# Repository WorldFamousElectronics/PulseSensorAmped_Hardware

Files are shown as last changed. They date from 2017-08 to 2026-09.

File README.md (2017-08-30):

# PulseSesorAmped_Hardware
These files were created in [Design Spark](http://www.designspark.com/) Schematic Layout and PCB Capture Software 

You will need to copy the contents of DesignSparkLibraryFiles into the default Library that Design Spark uses. Normally something like 

`Documents\DesignSpark PCB\Library`

This is the only way you will be able to use or modify the APDS-9008 part or the reverse mount LED part.

CONTRIBUTORS BACKTRACK AND NOTIFICATION

joel@pulsesensor.com
yury@pulsesensor.com

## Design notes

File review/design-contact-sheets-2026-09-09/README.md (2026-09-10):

# PulseSensor design contact sheets — 2026-09-09

DEVELOPMENT / visual reference review only. No board design changes or fabrication release.

27 numbered designs, paired front/back. Missing views are labeled; no different board is substituted. The nine SVG concepts are back-only illustrations. Existing renders are resized and padded faithfully, with no crop, recoloring, or reconstruction. Render colors may differ from intended manufacturing colors.

## Contact sheets

### Sheet 01: designs 01–03
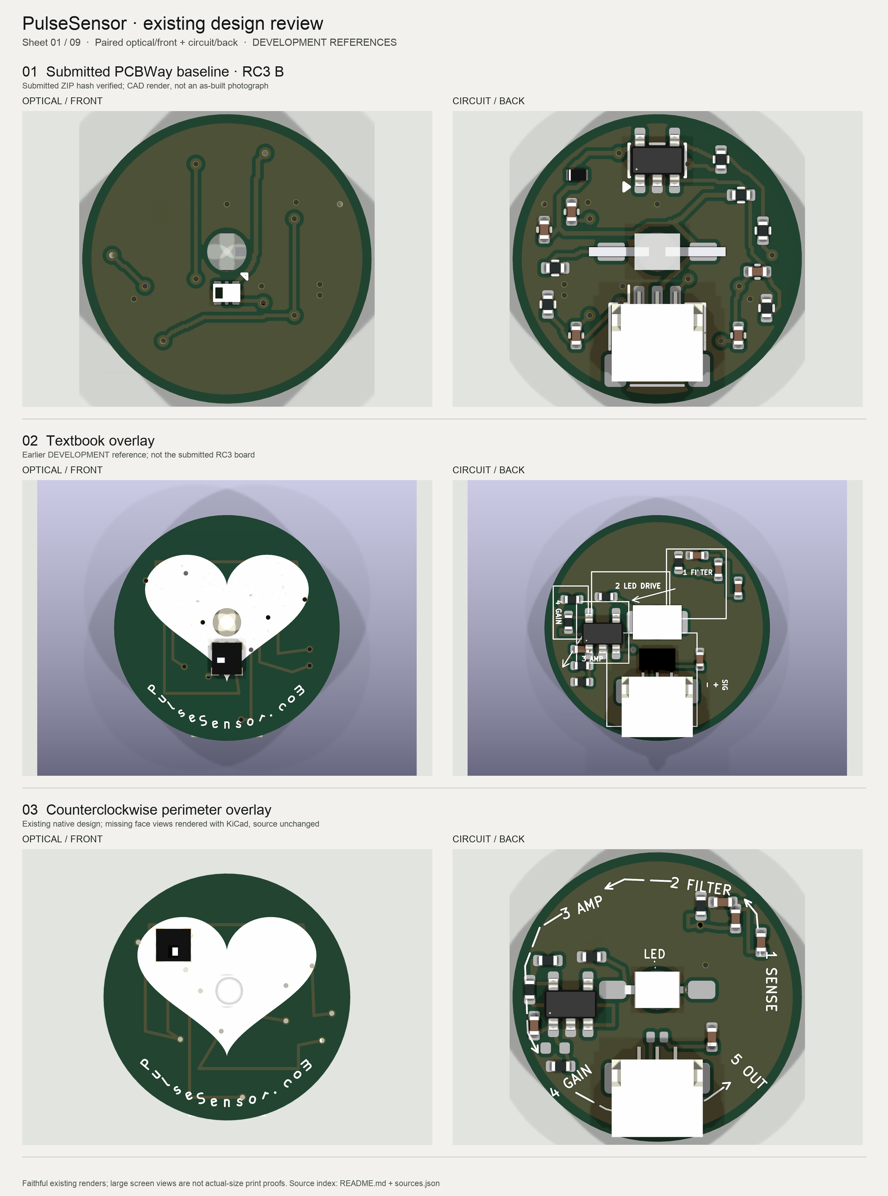
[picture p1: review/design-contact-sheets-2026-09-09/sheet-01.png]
Sheet 01


### Sheet 02: designs 04–06
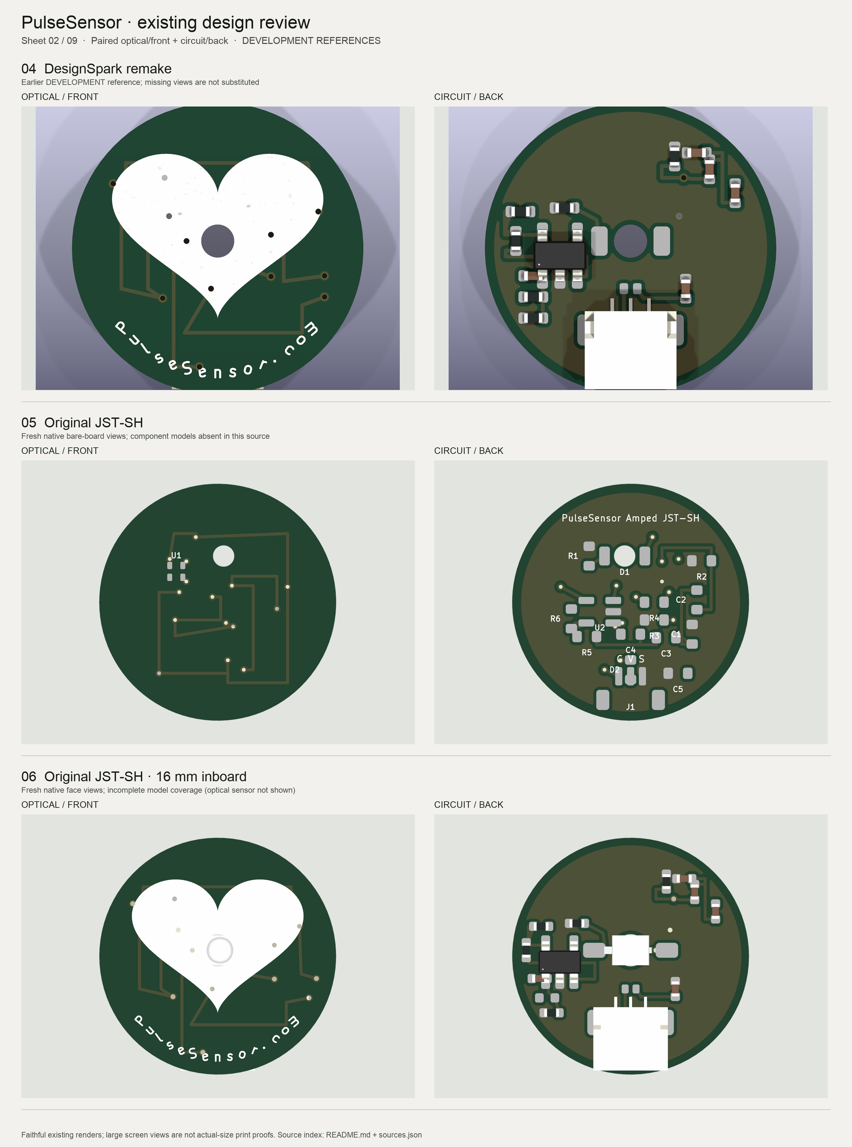
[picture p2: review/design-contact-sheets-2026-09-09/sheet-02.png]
Sheet 02


### Sheet 03: designs 07–09
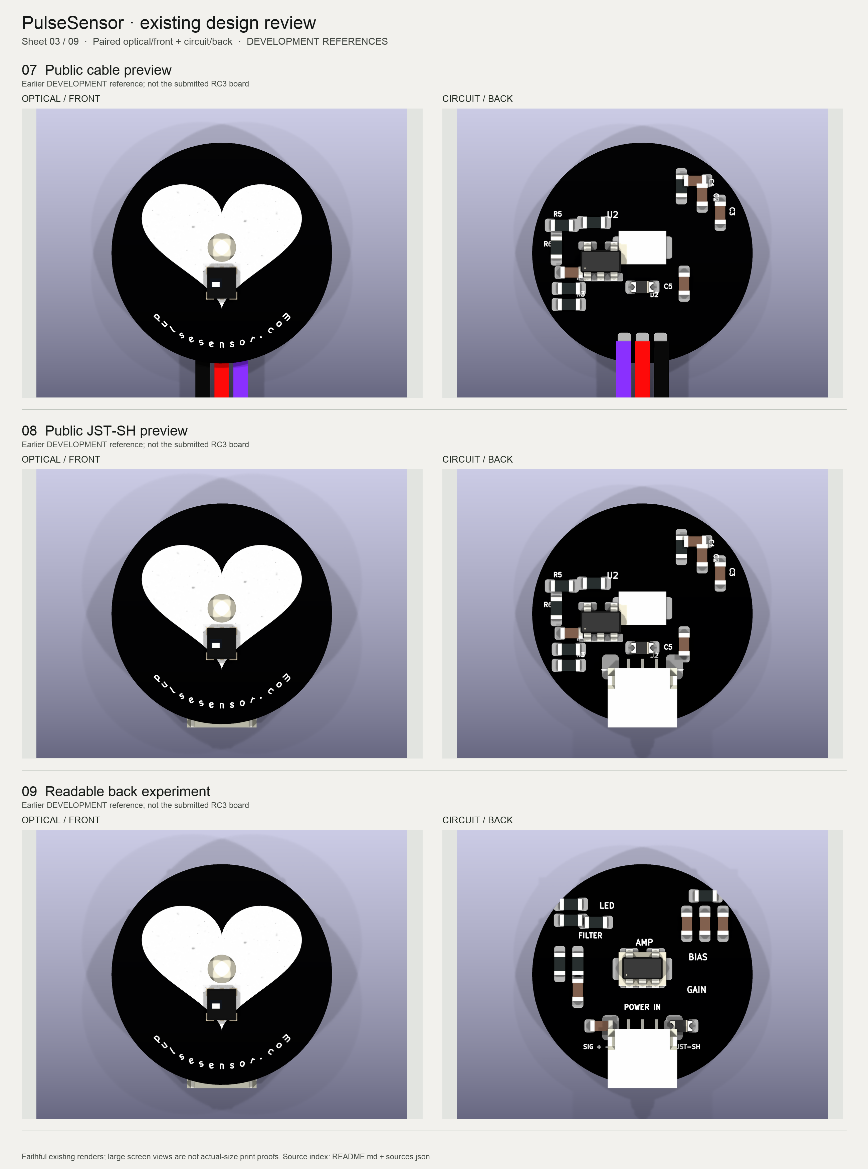
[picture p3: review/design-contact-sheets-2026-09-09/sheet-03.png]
Sheet 03


### Sheet 04: designs 10–12
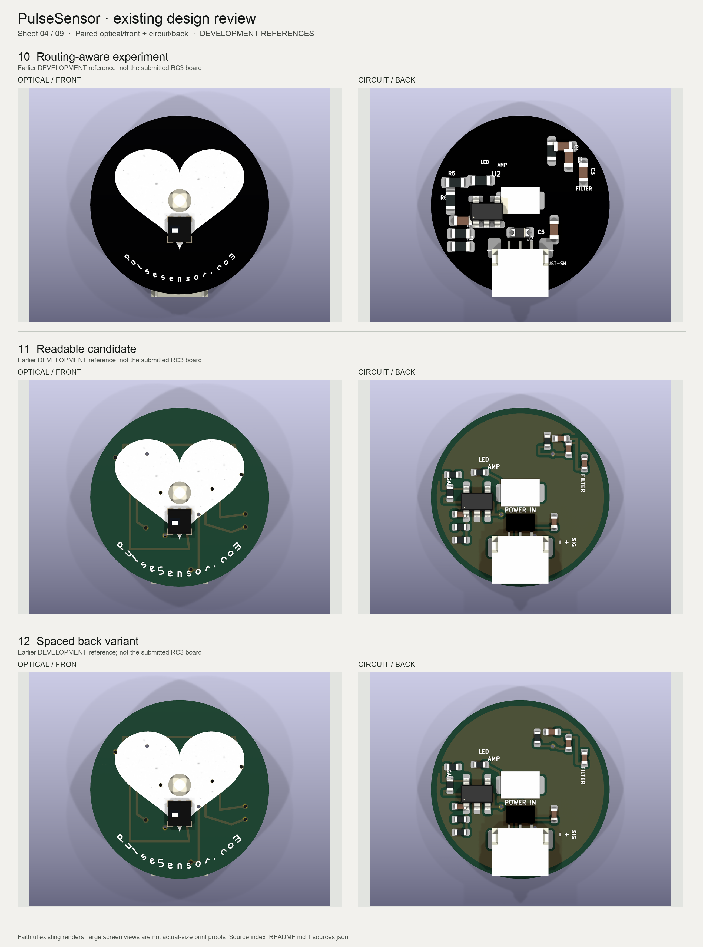
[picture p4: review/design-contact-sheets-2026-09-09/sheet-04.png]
Sheet 04


### Sheet 05: designs 13–15
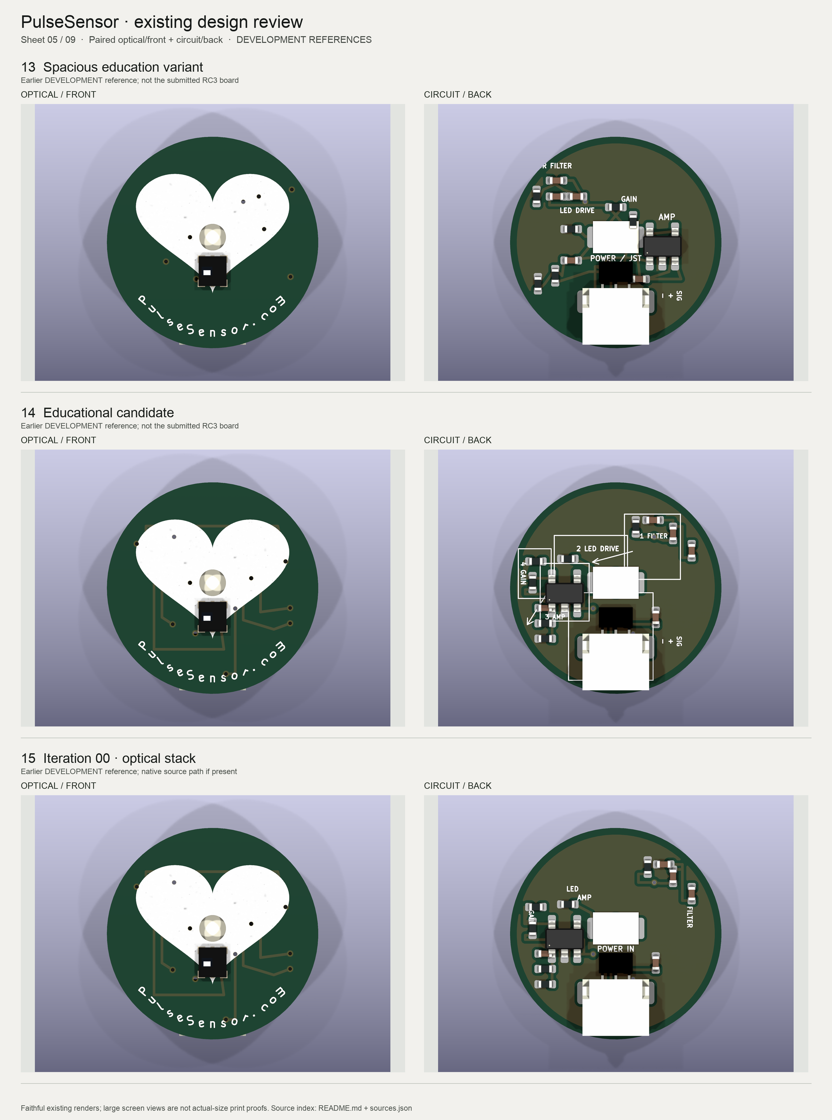
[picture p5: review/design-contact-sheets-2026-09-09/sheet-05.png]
Sheet 05


### Sheet 06: designs 16–18
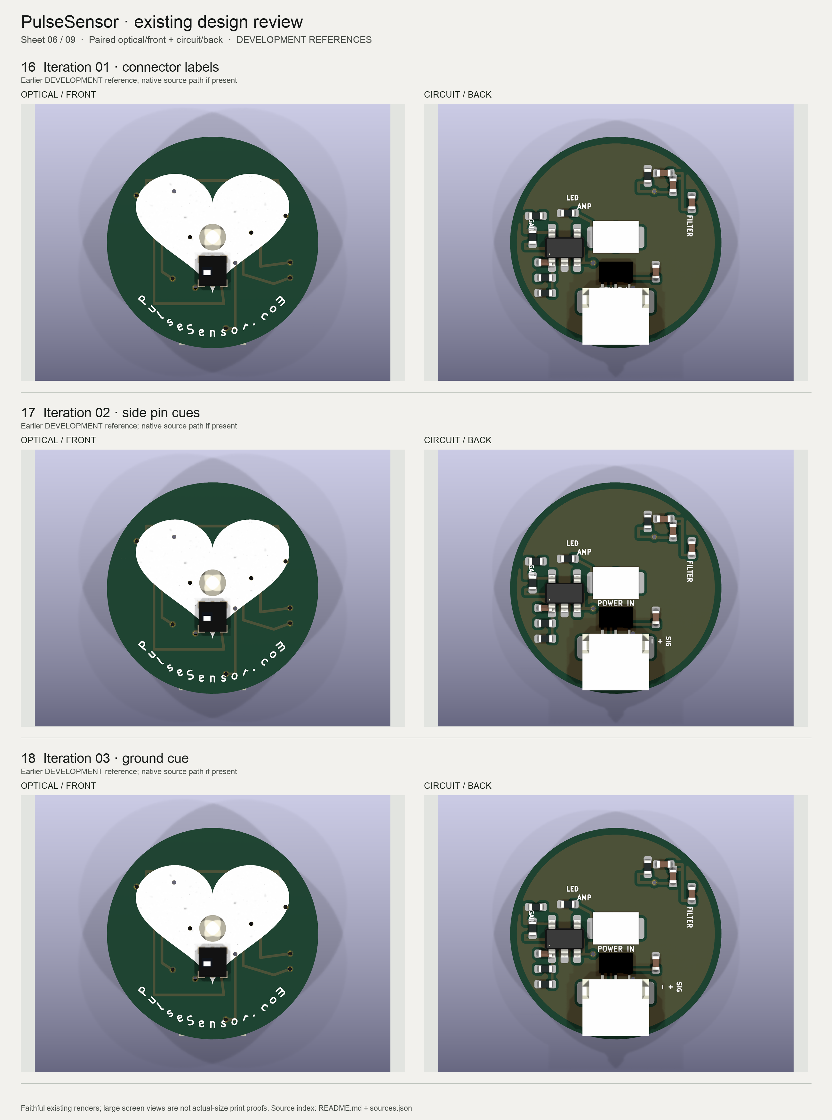
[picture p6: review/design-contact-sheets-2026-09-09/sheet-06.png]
Sheet 06


### Sheet 07: designs 19–21
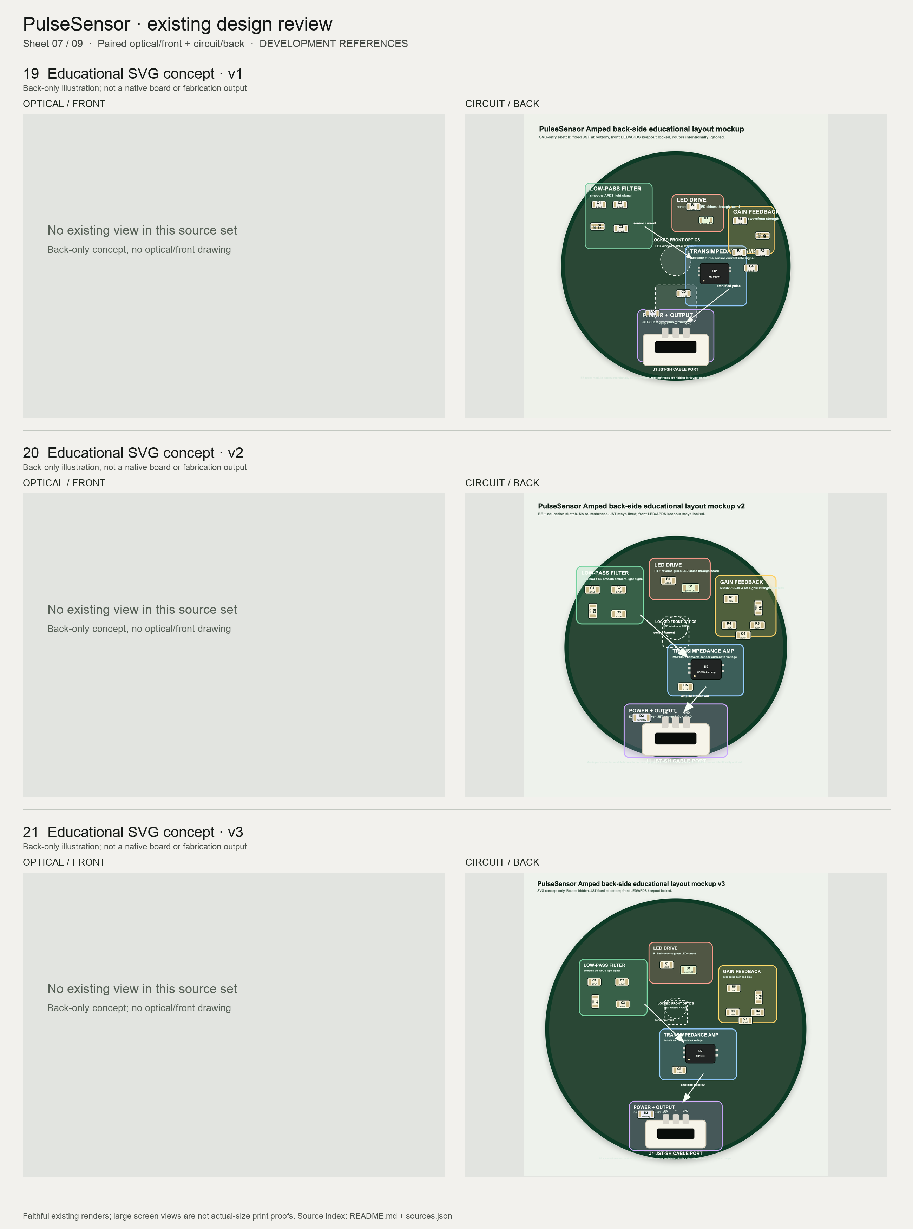
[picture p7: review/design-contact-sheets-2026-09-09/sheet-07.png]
Sheet 07


### Sheet 08: designs 22–24
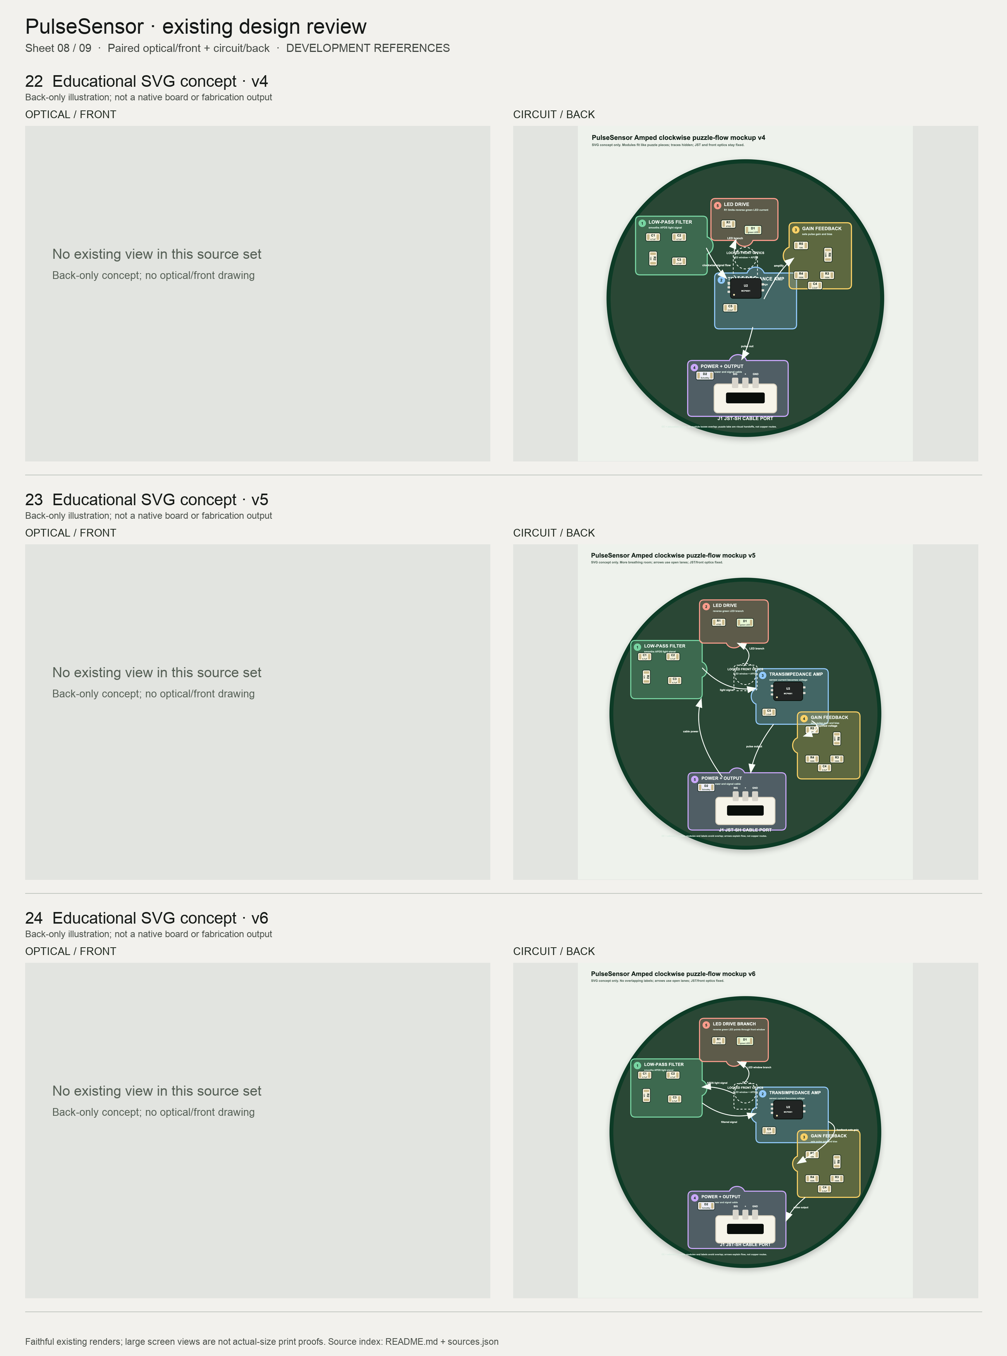
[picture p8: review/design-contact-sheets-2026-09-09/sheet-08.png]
Sheet 08


### Sheet 09: designs 25–27
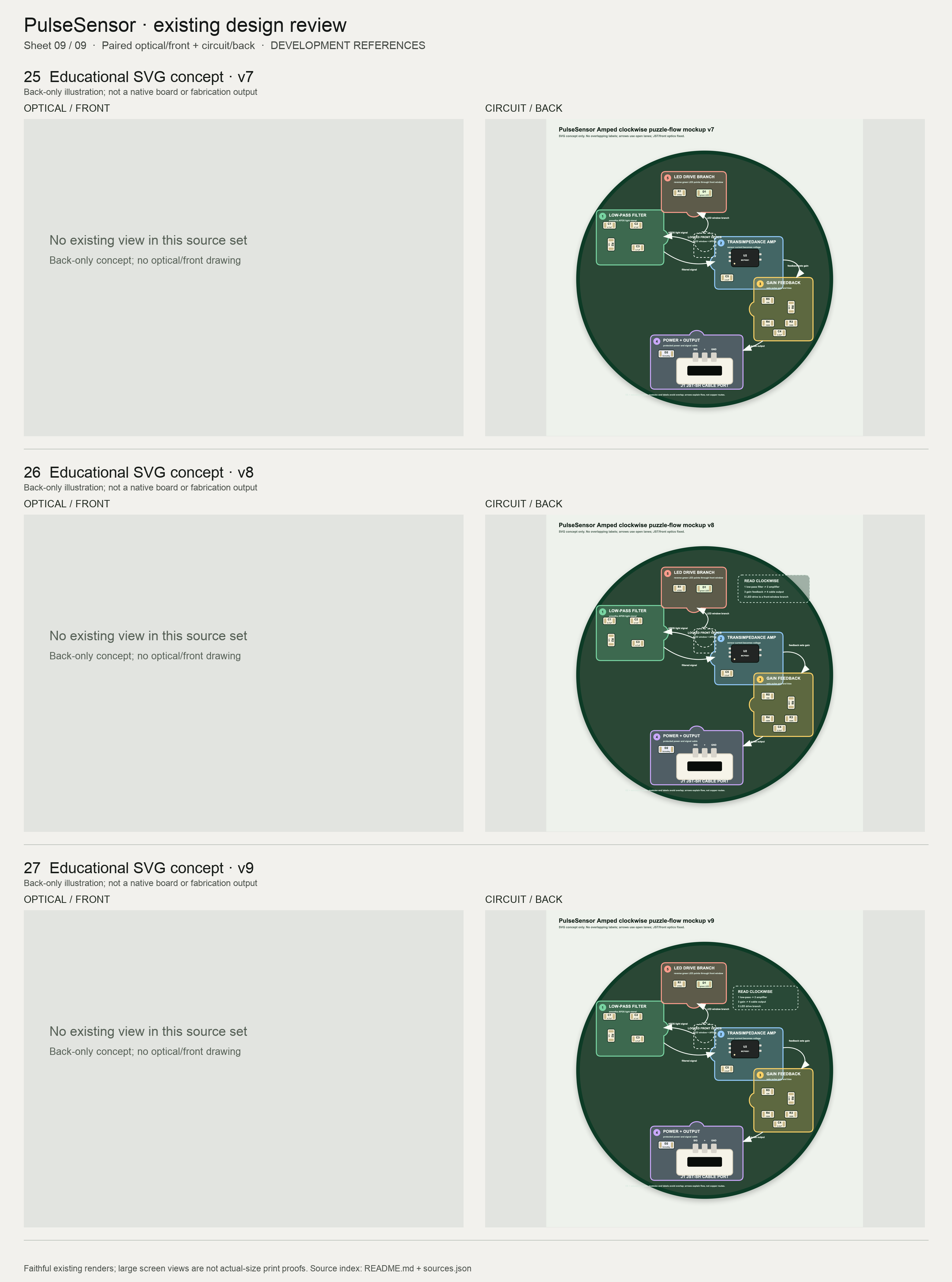
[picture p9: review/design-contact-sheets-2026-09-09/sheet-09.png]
Sheet 09


## Source index

Exact local source paths, SHA-256 hashes, source checkout revisions, tracked flags, and per-file dirty status are in [sources.json](sources.json). A checkout revision alone does not identify dirty or ignored artifacts: use the recorded file hash. Source files remain untouched.

| No. | Design | Source folder / native file |
| --- | --- | --- |
| 01 | Submitted PCBWay baseline · RC3 B | `PulseSensor-Amped-Rebuild/output/pcbway-release-candidates-RC3-R1-FINAL/PulseSensor-Amped-B-PCBWay-EVT-RC3-R1-FINAL/SOURCE_SUPPORT/PulseSensor-Amped-B-JST.kicad_pcb` |
| 02 | Textbook overlay | `Public-Online-Audit/KiCad-Public-3D-View-JSTSH-Textbook-Overlay-Variant/PulseSensorAmped_Public_Online_3D_View_JSTSH_Textbook_Overlay_Variant.kicad_pcb` |
| 03 | Counterclockwise perimeter overlay | `PCBWay-Fresh-Spin-2026-07-31-Isolated/02-counterclockwise-overlay/PulseSensorAmped_Fresh_CCW_Overlay.kicad_pcb` |
| 04 | DesignSpark remake | `KiCad-DesignSpark-Remake/PulseSensorAmped_DesignSpark_Remake.kicad_pcb` |
| 05 | Original JST-SH | `KiCad-Original-JSTSH/PulseSensorAmped_Original_JSTSH.kicad_pcb` |
| 06 | Original JST-SH · 16 mm inboard | `KiCad-Original-JSTSH-16mm-inboard/PulseSensorAmped_Original_JSTSH_16mm_inboard.kicad_pcb` |
| 07 | Public cable preview | `Public-Online-Audit/KiCad-Public-3D-View/PulseSensorAmped_Public_Online_3D_View.kicad_pcb` |
| 08 | Public JST-SH preview | `Public-Online-Audit/KiCad-Public-3D-View-JSTSH-Variant/PulseSensorAmped_Public_Online_3D_View_JSTSH_Variant.kicad_pcb` |
| 09 | Readable back experiment | `Public-Online-Audit/KiCad-Public-3D-View-JSTSH-Readable-Back-Experiment/PulseSensorAmped_Public_Online_3D_View_JSTSH_Readable_Back.kicad_pcb` |
| 10 | Routing-aware experiment | `Public-Online-Audit/KiCad-Public-3D-View-JSTSH-Routing-Aware-Experiment/PulseSensorAmped_Public_Online_3D_View_JSTSH_Routing_Aware.kicad_pcb` |
| 11 | Readable candidate | `Public-Online-Audit/KiCad-Public-3D-View-JSTSH-Readable-Production-Candidate/PulseSensorAmped_Public_Online_3D_View_JSTSH_Readable_Production_Candidate.kicad_pcb` |
| 12 | Spaced back variant | `Public-Online-Audit/KiCad-Public-3D-View-JSTSH-Spaced-Back-Variant/PulseSensorAmped_Public_Online_3D_View_JSTSH_Spaced_Back_Variant.kicad_pcb` |
| 13 | Spacious education variant | `Public-Online-Audit/KiCad-Public-3D-View-JSTSH-Spacious-Education-Variant/PulseSensorAmped_Public_Online_3D_View_JSTSH_Spacious_Education_Variant.kicad_pcb` |
| 14 | Educational candidate | `Public-Online-Audit/KiCad-Public-3D-View-JSTSH-Educational-Production-Candidate/PulseSensorAmped_Public_Online_3D_View_JSTSH_Educational_Production_Candidate.kicad_pcb` |
| 15 | Iteration 00 · optical stack | `Public-Online-Audit/Readable-Production-Design-Loops/iteration-00-fixed-optical-stack/renders/back.png` |
| 16 | Iteration 01 · connector labels | `Public-Online-Audit/Readable-Production-Design-Loops/iteration-01-connector-label-pass/renders/back.png` |
| 17 | Iteration 02 · side pin cues | `Public-Online-Audit/Readable-Production-Design-Loops/iteration-02-side-pin-cues/renders/back.png` |
| 18 | Iteration 03 · ground cue | `Public-Online-Audit/Readable-Production-Design-Loops/iteration-03-visible-ground-cue/renders/back.png` |
| 19 | Educational SVG concept · v1 | `Public-Online-Audit/Educational-SVG-Mockups/pulsesensor_back_educational_layout_mockup.svg` |
| 20 | Educational SVG concept · v2 | `Public-Online-Audit/Educational-SVG-Mockups/pulsesensor_back_educational_layout_mockup_v2.svg` |
| 21 | Educational SVG concept · v3 | `Public-Online-Audit/Educational-SVG-Mockups/pulsesensor_back_educational_layout_mockup_v3.svg` |
| 22 | Educational SVG concept · v4 | `Public-Online-Audit/Educational-SVG-Mockups/pulsesensor_back_clockwise_puzzle_flow_mockup_v4.svg` |
| 23 | Educational SVG concept · v5 | `Public-Online-Audit/Educational-SVG-Mockups/pulsesensor_back_clockwise_puzzle_flow_mockup_v5.svg` |
| 24 | Educational SVG concept · v6 | `Public-Online-Audit/Educational-SVG-Mockups/pulsesensor_back_clockwise_puzzle_flow_mockup_v6.svg` |
| 25 | Educational SVG concept · v7 | `Public-Online-Audit/Educational-SVG-Mockups/pulsesensor_back_clockwise_puzzle_flow_mockup_v7.svg` |
| 26 | Educational SVG concept · v8 | `Public-Online-Audit/Educational-SVG-Mockups/pulsesensor_back_clockwise_puzzle_flow_mockup_v8.svg` |
| 27 | Educational SVG concept · v9 | `Public-Online-Audit/Educational-SVG-Mockups/pulsesensor_back_clockwise_puzzle_flow_mockup_v9.svg` |

## Submitted baseline and reuse boundaries

Design 01 uses the render files and native supporting PCB from the submitted RC3 B archive. The local archive SHA-256 was recomputed as `0afda167b52ab0b0251cf22f91fd92fefa5dcf5e74f67b36446e7ec775acf792`; native PCB bytes were compared directly with its ZIP member. PCB SHA-256: `b439dcff82c4553731ac35ebcd27276899f8dfbbfcd35f2351d8101497eb4ad4`. This establishes archive identity, not as-built equivalence. The original manufacturing Gerbers, BOM and CPL control, rather than the supporting native file.

The submitted RC3 design has optical/front on KiCad B and circuit/back on KiCad F. Earlier versions use different conventions; the paired labels here follow their existing optical/front and circuit/back renders.

Textbook, educational-candidate, and counterclockwise versions demonstrate actual educational silkscreen graphics in native boards. These are block/flow illustrations, not a full component-symbol schematic. They are visual references on older electrical layouts. Their pin maps, geometry, topology and values must not replace the RC3 working baseline. The July counterclockwise folder explicitly declares itself non-authoritative and not for fabrication.

The old white heart and website geometry is photo-reconstructed artwork, not a recovered original silkscreen export (see `Original-Review/original_logo_source_audit.md` in the source checkout). No new artwork or board changes were made for this review.

## Reproduce

Run `build_contact_sheets.py` using Python with Pillow. It reads the approved WFE source checkout paths defined at the top and writes only this review directory. The source hashes record the exact visual inputs used. No email content or supplier correspondence is included.

## Render QA and limitations

All nine sheets were visually reviewed. Five missing/incorrectly named face views were rendered from unchanged existing native boards using KiCad; exact commands and before/after source-hash checks are in `rendered-missing-views/render-evidence.json`. Design 05 has no component models; design 06 has incomplete optical-sensor model coverage. These are source limitations, not assembly instructions. Design 04 also has incomplete legacy model coverage. No missing parts were invented. All native sources remain byte-for-byte unchanged.

## Added artwork, routing and power/color revisions

Original sheets 01–09 remain unchanged. This appendix adds corrected teaching artwork, retained native routing/artwork milestones, and the enlarged-front / color-print candidates. Metadata-helper failures are explicitly labeled. All partial routing checkpoints remain linked in the local visual ledger.

[sheet-10.png](sheet-10.png)

[sheet-11.png](sheet-11.png)

[sheet-12.png](sheet-12.png)

[sheet-13.png](sheet-13.png)

[sheet-14.png](sheet-14.png)

[sheet-15.png](sheet-15.png)

[sheet-16.png](sheet-16.png)

[sheet-17.png](sheet-17.png)

[sheet-18.png](sheet-18.png)

[sheet-19.png](sheet-19.png)

[Current review](../power-color-2026-09-09/review.html) · [All routing attempts and native revision history](../sendoff-candidate-2026-09-09/visual-log/index.html)

### Final selected comparison — sheet 20

[Sheet 20](sheet-20.png) adds the final color-10 candidate. Color-09 on sheet 19 is superseded; its brown optical-front rendering is a retained renderer defect, not intended solder mask. Color-10 still encounters KiCad mixed-mask rendering limitations; the shared black optical-face design is shown from verified mono-08.

## Packaging postcard milestone — 2026-09-10

[Sheet 21](sheet-21.png) shows both 4-inch insert faces: PCB/reference BOM and matching schematic. [Print files and source](../postcard-insert-2026-09-10/README.md). The color-10 board back is accepted as a major milestone; front board graphics are deferred. No hardware geometry changed.

## Complete schematic companion — 2026-09-10

[Sheet 22](sheet-22.png) adds a separate 4-inch card with the complete circuit and a six-part reading guide. [Print files, source and preserved draft](../schematic-companion-2026-09-10/README.md). The first PCB/BOM card and all hardware remain unchanged.

## Puzzle module alternative — 2026-09-10

[Sheet 23](sheet-23.png) compares accepted color-10 with interlocking solid-color functional areas. [Vector study and revision record](../puzzle-modules-2026-09-10/README.md). No hardware changes.

## Dotted module alternative — 2026-09-10

[Sheet 24](sheet-24.png) compares accepted color-10 with straight solid-color functional areas with black dotted boundaries. [Vector study and revision record](../module-outlines-2026-09-10/README.md). No hardware changes.

## Full-color full schematic retail purchase card — 2026-09-10

[Sheet 25](sheet-25.png) adds a separate 4-inch card with the complete circuit and a parts schedule. [Print files, source and preserved draft](../full-color-retail-card-2026-09-10/README.md). The first PCB/BOM card and all hardware remain unchanged.

## Brand unification — 2026-09-10

[Sheet 26](sheet-26.png) shows matching website-sourced salmon and neutral colors on the board and both purchase-card faces. [Palette evidence, print PDFs and color-only checks](../brand-unification-2026-09-10/README.md). All earlier geometry and text preserved.

## WebSerial color iteration — 2026-09-10

[Sheet 27](sheet-27.png) shows matching WebSerial accent colors on the board and both purchase-card faces. [Palette evidence, print PDFs and color-only checks](../webserial-palette-2026-09-10/README.md). All earlier geometry and text preserved.

## WebSerial color iteration — 2026-09-10

[Sheet 28](sheet-28.png) shows matching WebSerial accent colors on the board and both purchase-card faces. [Palette evidence, print PDFs and color-only checks](../led-green-power-red-2026-09-10/README.md). All earlier geometry and text preserved.

## Quiet engineering trial — 2026-09-10

[Sheet 29](sheet-29.png) shows muted board colors and matching pale card tints on the board and both purchase-card faces. [Palette evidence, print PDFs and color-only checks](../quiet-engineering-2026-09-10/README.md). All earlier geometry and text preserved.

## Six-color brand trial — 2026-09-10

[Sheet 30](sheet-30.png) shows white, black, red, green, gray and beige on the board and both purchase-card faces. [Palette evidence, print PDFs and color-only checks](../six-color-brand-2026-09-10/README.md). All earlier geometry and text preserved.

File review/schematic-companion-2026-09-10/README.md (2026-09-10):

# Complete schematic companion postcard

Classification: DEVELOPMENT packaging review proof for the JST revision. This does not promote the board to shipping-product status.

Separate two-sided 4 × 4 inch card, accompanying the [PCB, legend and reference BOM card](../postcard-insert-2026-09-10/README.md).

- Face A: complete connected circuit, organized into six numbered sections. Every chip and connector pin is explicit, including U1's three intentional no-connects. Matching labels connect between sections; B is the filter-to-amplifier connection.
- Face B: matching six-part reading guide and symbol key. Hardware only.
- Source: color-10 native schematic/netlist. All 16 components and 40 terminals (37 connected + 3 NC) checked against the independent terminal map. PDF wires were inspected visually, not extracted by an electrical connectivity engine.
- R1 is described by function; no numerical resistance is invented. Full reference BOM accompanies this on card 01.
- Vector type and schematic: 6.48 pt pin numbers, 6.72 pt component labels, 7.2 pt reading-guide body. Colors supplement labels; meaning does not depend on color alone.

## Files

[4-inch print PDF](output/pdf/PulseSensor-complete-schematic-4x4.pdf), two 288 × 288 pt pages.

[PDF with 0.125-inch bleed](output/pdf/PulseSensor-complete-schematic-4x4-bleed.pdf), two 306 × 306 pt pages with explicit 288 pt trim boxes.

[Visual review](review.html) · [Contact sheet 22](../design-contact-sheets-2026-09-09/sheet-22.png) · [Verification](verification.json).

The first layout proof is preserved in `iterations/01-complete-schematic/`. The final version fixes crowded diode/filter labels, guide line spacing, and explicitly draws U2's supply connections. Board art and first-card files are unchanged.

## Rebuild

Use the bundled Python runtime with ReportLab, pypdf and Pillow:

```
python3 build_companion.py
python3 verify_card.py
pdftoppm -scale-to 1400 -png output/pdf/PulseSensor-complete-schematic-4x4.pdf output/card
python3 log_companion.py
```

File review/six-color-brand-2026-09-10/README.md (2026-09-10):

# Six-color brand trial

Classification: DEVELOPMENT appearance and packaging review.

[Overview](six-color-overview.png) · [Board vector](six-color-07-back.svg) · [Print card](output/pdf/six-color-retail-purchase-card.pdf) · [Bleed card](output/pdf/six-color-retail-purchase-card-bleed.pdf).

Restricted to white, black, PulseSensor red #FF5A5F, WebSerial LED green #44FF44, gray #C0C0C0 and beige #E7DDC8. Green remains LED; red remains power. Board amplifier area is black with white lettering; lighter areas have black lettering. Card amplifier area uses gray, with black reserved for its schematic and text for readability. Beige supplies the warm packaging tone.

Layouts, physical components and circuit connections remain unchanged. Board label polygons are split at the existing dark-region boundary only to change their fill; no footprint or electrical edits. All 40 terminals in the independent map match the native source and both PDF sizes are checked. Prior versions retained; sheet 30, artifact 67.

This is an appearance study. Manufacturer considerations remain in the prior quiet-engineering reality check; no fabrication files were submitted or ordered.

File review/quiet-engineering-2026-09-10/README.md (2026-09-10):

# Quiet engineering palette trial

Classification: DEVELOPMENT appearance and packaging review.

[Overview](quiet-overview.png) · [Board before/after](board-comparison.png) · [Manufacturer reality check](manufacturer-reality-check.md).

Muted green LED, warm red power, teal filter, slate-blue amplification, dusty-violet bias and neutral-gray sense. White labels on the deep board colors; dark ink over related pale tints on warm-white card stock. This adapts the brand direction rather than claiming exact website color tokens.

Calculated sRGB label contrast: board 5.06–6.42:1; card primary ink 9.77–10.10:1, secondary ink at least 5.96:1. Black board boundaries are at least 3.27:1 against the fills. These are screen checks, not certification of printed legibility or color-vision accessibility. Labels, references, boundaries and the schematic carry meaning independently of color.

[Palette and checks](palette.json) · [Verification](verification.json) · [Board vector](quiet-06-back.svg).

[4-inch card PDF](output/pdf/quiet-engineering-retail-purchase-card.pdf) · [Bleed PDF](output/pdf/quiet-engineering-retail-purchase-card-bleed.pdf).

All board geometry and non-color PDF drawing instructions are unchanged from the earlier layouts; all 40 terminals in the independent map match the CAD netlist. No native hardware changes. Contact sheet 29, artifact 66. Previous versions preserved.

Rebuild with `build_board.py`, `build_card.py`, Poppler, `verify_palette.py` and `log_palette.py`. The supplier note is based on published specifications, not contacted-vendor approval.

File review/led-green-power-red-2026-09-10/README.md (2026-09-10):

# Green LED / red power correction

Classification: DEVELOPMENT appearance and packaging review.

LED backgrounds are now green #44FF44. Power backgrounds are now coral red #FF6B6B. Applied to the board, full schematic and corresponding BOM rows. Other colors, text and geometry are unchanged. The colors come from the previously verified WebSerial palette.

[Overview](led-green-power-red-overview.png) · [Board SVG](led-green-power-red-05-back.svg) · [Print PDF](output/pdf/led-green-power-red-retail-purchase-card.pdf) · [Bleed PDF](output/pdf/led-green-power-red-retail-purchase-card-bleed.pdf).

Exact board geometry and non-color PDF operators remain verified against the earlier layouts. All 40 terminals in the independent map match the native netlist. No CAD changes. Previous iterations retained; contact sheet 28, artifact 65.

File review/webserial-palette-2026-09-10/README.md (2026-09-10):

# WebSerial bright palette iteration

Classification: DEVELOPMENT appearance and packaging review, 2026-09-10.

[Board + card overview](webserial-overview.png) · [Board comparison](board-comparison.png) · [Review](review.html).

Uses exact accent colors from the [live PulseSensor WebSerial example](https://worldfamouselectronics.github.io/PulseSensorPlayground/webserial-explainer/), linked by the [PulseSensor WebSerial guide](https://pulsesensor.com/pages/pulsesensor-and-webserial).

| Board/card area | Color | WebSerial source role |
| --- | --- | --- |
| LED | #FF6B6B coral | Signal, heart and buttons |
| Sense | #44FF44 lime | BPM and live data |
| Filter | #51CF66 green | Connected indicator |
| Amp / gain | #64C8FF sky blue | Beat value |
| Bias | #FFAA44 orange | IBI and method highlights |
| Power | #CCCCCC gray | Method text |

These are visual palette assignments, not equivalences between physical circuit stages and dashboard measurements. Black labels, white page backgrounds, existing dotted board boundaries and the full continuous schematic layout remain unchanged.

[Palette evidence](sources/palette-evidence.json) · [Geometry and PDF verification](verification.json).

[Board SVG](webserial-04-back.svg) · [Board PNG](webserial-04-back.png).

[4-inch PDF](output/pdf/webserial-full-color-full-schematic-retail-purchase-card.pdf) · [0.125-inch bleed PDF](output/pdf/webserial-full-color-full-schematic-retail-purchase-card-bleed.pdf).

Board SVG geometry and all non-color PDF drawing operators match the previous layouts exactly. Native hardware was not modified. This is an appearance/packaging iteration, not revised board fabrication output. All earlier versions remain available in the visual log; this is contact sheet 27, artifact 64.

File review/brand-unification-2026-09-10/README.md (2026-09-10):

# PulseSensor brand unification

Classification: DEVELOPMENT appearance and packaging review, 2026-09-10.

[Unified preview](brand-overview.png) · [Board before/after](board-comparison.png) · [Review](review.html).

This iteration changes colors only, preserving the dotted-boundary board and the full-color full schematic retail purchase card layout, typography, wording, BOM, symbols and connections. The white/cream component rendering is now neutral white/gray; this is a positioning proof, not a claim about actual component material colors.

## Website palette

The palette was verified against the [live PulseSensor theme stylesheet](https://pulsesensor.com/cdn/shop/t/51/assets/theme.scss.css?v=170999498476908761131787148316) and [homepage](https://pulsesensor.com/) on 2026-09-10, with the Lab and Research pages also inspected. These are observed live website colors, not a claimed formal brand guide.

| Function | Board and card background |
| --- | --- |
| LED | Salmon #FF5A5F |
| Bias | Pale pink #FFF0F0 |
| Sense | Light gray #EEEEEE |
| Power | Gray #DADADA |
| Filter | Gray #C0C0C0 |
| Amp / gain | Gray #B3B3B3 |

Black #000000 ink and white #FFFFFF paper; secondary card text #333333. Board labels are black for contrast on the lighter backgrounds. No additional research accent was necessary. [Exact evidence excerpts](sources/palette-evidence.json) and [palette](palette.json) are saved. Full fetched public HTML/CSS is ignored by Git.

## Artifacts and validation

[Board SVG](brand-03-back.svg) · [Board PNG](brand-03-back.png).

[4-inch PDF](output/pdf/brand-full-color-full-schematic-retail-purchase-card.pdf) · [0.125-inch bleed PDF](output/pdf/brand-full-color-full-schematic-retail-purchase-card-bleed.pdf).

`verify_brand.py` checks all 40 native terminals in the independent map, PDF page/trim dimensions, and public hardware-only text. It additionally compares every board SVG geometry attribute with the prior version and all non-color PDF drawing operators with the prior card: exact matches. [Verification](verification.json).

No CAD, copper, mask, placement, optical or prior artifact files changed. Supplier-ready separations for the board remain outside this appearance iteration. Card print files retain the same dimensions.

Rebuild with `build_board.py`, `build_card.py`, Poppler, `verify_brand.py`, and `log_brand.py`. Contact sheet 26 preserves this iteration alongside the earlier alternatives.

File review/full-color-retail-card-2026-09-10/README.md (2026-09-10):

# Full-Color Full Schematic Retail Purchase Card

Classification: DEVELOPMENT packaging review proof, JST revision.

A two-sided 4 × 4 inch card styled as a mid-century electronics assembly guide: cream paper, restrained print tints, black linework, zigzag resistor symbols, ruled headings, and a parts schedule. This is new artwork inspired by the era, not a historical document.

Face A places one continuous signal path, feedback loop and VREF connection across the six functional background hues, without separated module diagrams. Standard matching power, ground and OUT labels connect the remaining common nodes. Every component and chip/connector pin is included, including intentional U1 NC pins. Tints are lighter versions of the board module palette for black-ink readability.

Face B provides the public reference BOM and short reading guide. R1 is described by function; no resistance is invented or internal test information printed.

[Print PDF](output/pdf/full-color-full-schematic-retail-purchase-card.pdf) · [Bleed PDF](output/pdf/full-color-full-schematic-retail-purchase-card-bleed.pdf) · [Preview](output/retail-card-preview.png) · [Verification](verification.json).

Trim: 288 × 288 pt. Bleed version: 306 × 306 pt, 0.125 inch each side. Body and labels are 6.24–7.2 pt at trim size. The terminal map is checked against the native netlist; vector wiring is reviewed visually, not automatically extracted from the PDF. No native hardware or previous card was altered.

First layout retained in `iterations/01-layout/`. Rebuild with `build_card.py`, render using Poppler, validate with `verify_card.py`, and update contact sheet 25 using `log_card.py`.

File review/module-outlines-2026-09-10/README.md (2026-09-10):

# Dotted module outline iteration

Classification: DEVELOPMENT appearance study.

[Back preview](modules-02-back.png) · [Vector proof](modules-02-back.svg) · [Comparison with puzzle tabs](comparison.png).

The six background colors and functional regions are retained. Puzzle tabs are removed; straight shared boundaries use black circular dots, nominally 0.14 mm diameter with 0.28 mm spacing. Dots are module outlines, not current paths.

Component bodies, pads, LED, optical geometry, labels and polarity marks retain their native coordinates. No CAD files were changed. Prior puzzle iteration and accepted color-10 remain preserved. This is an appearance proof, not fabrication output.

Rebuild with `build_modules.py`; update contact sheet 24 using `log_iteration.py`.

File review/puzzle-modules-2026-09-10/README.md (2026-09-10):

# Puzzle module background iteration

Classification: DEVELOPMENT appearance study, 2026-09-10.

[Comparison](comparison.png) · [Back preview](puzzle-01-back.png) · [Editable vector proof](puzzle-01-back.svg) · [Visual history](review.html).

Six complementary colored areas replace the routed-net overlays, ground-plane shading, pad halos and dotted signal guides. Rounded puzzle tabs connect the visual regions:

- Teal: FILTER (C1, C3, C4).
- Purple: AMP + GAIN (U2, R5, R6).
- Berry: BIAS (R3, R4).
- Ochre: LED (D1, R1).
- Green: SENSE / input coupling (R2, C2; U1 is on the opposite face).
- Blue: POWER / connector (D2, C5, J1).

Colors describe functional areas, not shared electrical nets. White component references, module names and + / - markings remain. Shape seams are nominally 0.11 mm. Native component and pad geometry were copied in their exact board coordinates from color-10; no copper, footprint, LED or optical geometry was edited. The accepted back and deferred front artwork remain unchanged.

This is a vector positioning/appearance proof, not revised fabrication output. Color printing separations and supplier print review have not been prepared for this alternative.

`build_puzzle.py` rebuilds the SVG and PNG from existing native-derived vector polygons using Shapely and Pillow. It does not repaint raster board images. `log_iteration.py` appends contact sheet 23 and artifact 60. The first fit is retained in `iterations/01-first-fit/`; final cleanup removes tiny residual dotted-guide fragments from the source label polygons.

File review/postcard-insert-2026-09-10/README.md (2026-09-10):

# PulseSensor hardware postcard insert

DEVELOPMENT / packaging proof for the JST educational board. 2026-09-10.

## Accepted scope

Yury accepted the color-10 PCB back as a major milestone on 2026-09-10. Its source and graphics are unchanged. Front PCB graphic design is deferred. This work creates a packaging insert only.

The insert is hardware-only: exact PCB artwork, simplified schematic, reference BOM, color legend and TL;DR. It contains no fingers, anatomy, PPG explanation, or sensing-science illustration. A first image-generation direction was rejected by the user and is excluded from every final print file.

## Deliverables

- `output/PulseSensor-4x4-card.pdf`: two upright 4 × 4 inch faces.
- `output/PulseSensor-4x4-card-bleed.pdf`: two 4.25 × 4.25 inch pages, 4 × 4 trim box and 0.125 inch bleed on each edge.
- `output/card-1.png`, `output/card-2.png`: rendered review proofs.
- `build_postcard.py`: editable vector layout and schematic source, using ReportLab and embedded Arial fonts.

Print at 100%, with no fit-to-page scaling. Both faces are upright; the printer should confirm duplex orientation and paper/ink profile. Body/BOM text is approximately 7–9 points; schematic labels are 6.5 points. Inspect a physical-size proof before a packaging run. RGB artwork and colors require the printer's normal color conversion; this is not a certified PDF/X press profile.

## Accuracy and reading conventions

The board image is the unchanged `power-color-2026-09-09/color-10/back.png` artwork. It is a CAD-aligned illustration, enlarged on the postcard. U1 is on the other face and is explicitly identified as such.

The schematic is a manually laid-out, simplified electrical diagram. The 16 component references and 37 connected terminals were checked against the native exported netlist; see verification.json for the exact counted terminal total. Named labels carry shared connections: +V is input supply, PROT is the supply after D2, VREF is the bias midpoint, and OUT is J1 pin 3. U2's supply rails are stated as named connections; unused U1 pins are omitted. The LED branch remains electrically separate from the signal chain.

The compact BOM groups identical values. R1 is identified by its current-limit function because no single numeric resistance is established in the selected reference. No internal testing/population wording appears on the postcard. The table is a reader's reference, not an assembly purchasing BOM; full orderable MPNs and assembly instructions remain in the hardware package.

## Visual history and generation

`iterations/01-hardware-map` retains the first hardware-only proof; `iterations/02-bom-fit` retains the first BOM layout before margin refinements; `iterations/03-margin-check` retains the last spacing proof. The final postcard is appended to the shared contact sheets as sheet 21.

The built-in image-generation tool was used for an initial illustration concept, which the user rejected. The final PCB is existing native artwork; the schematic, BOM and text are vector-authored for fidelity and print clarity. No generated biology artwork is used in the final design. No PCB edits, supplier message, packaging order, or public product promotion was made.

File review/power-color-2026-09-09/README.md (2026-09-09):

# PulseSensor — larger front, polarity and full-color paths

DEVELOPMENT / manufacturing REVIEW candidates • 2026-09-09

Selected monochrome revision: **mono-08**. Selected PCBWay full-color iteration: **color-10**. Earlier mono-06 and color-07 are retained; the minus sign and LED-current arrow color were refined after viewing them. Color-09 retains a rejected renderer-color checkpoint; color-10 uses explicit opaque RGBA color metadata. KiCad still applies the F mask appearance across its render of both faces. Therefore the intended optical-front view uses mono-08, whose B-side geometry and black mask are identical. The uncorrected color-10/front.png render is retained as renderer evidence, not the intended optical finish.

## Front

The curved pulsesensor.com wordmark now has **1.35 mm x-height**, up from 0.80 mm (68.8%). This is the largest fit found in a 0.01 mm height / 0.025 mm radius search with the selected Arial Bold outlines, tracking and at least 0.20 mm wordmark-to-heart and edge gaps. It is not a claim that no other font/layout could be larger. A 0.20 mm rounding operation softens the bottom tip. The source website badge and optical macro photograph were visually inspected. The heart is still a reconstruction, not recovered historical-master artwork.

- [Website badge](https://pulsesensor.com/cdn/shop/files/1_150x@2x.png?v=1690061808)
- [Official optical front macro photograph](https://pulsesensor.com/cdn/shop/products/PulseSensorAmpedFinger-web_2_grande.jpg)

The optical window, D1, U1, every other footprint, copper segment, via, copper zone and board outline are unchanged from candidate-05. All five new native revisions passed that exact structural comparison. All have zero unconnected nets, zero schematic mismatches and only the original optical courtyard exception.

## Back and color key

- **Red:** positive input supply, /VDD_IN.
- **Amber:** diode-protected supply, /VDD_PROTECTED; also the separate LED cathode/current-limiting branch /LED_K. These are different nets: similar color does not connect them.
- **Cyan:** ground connections; **dark blue area:** the actual F-side ground plane, geometrically simplified for printing.
- **Purple:** retained logical signal guides.
- **+ / −:** supply and ground reference near the JST connector. Minus means GND / 0 V, not a separate negative-voltage supply. Pin 1 ground, pin 2 supply, pin 3 signal.

Solid colored routes follow F copper segments. Dashed colored routes project B-side segments into the same top view; they are not exposed F-side metal. Gaps keep labels and solder openings clear. A ground plane distributes return current across an area; its fill is not a prescribed single current trajectory. The LED current arrow is amber and points from the LED cathode toward R1. The purple circuit path represents signal processing, not DC passing through capacitor dielectric.

All colored routes are **printed ink over intact solder mask**. No copper has been exposed and no electrical rerouting was needed. The full-color back preview is a CAD-aligned vector positioning proof with schematic component bodies, not a photorealistic 3D rendering. The front and monochrome views are KiCad 3D renders; source model/tented-via appearance limitations remain.

## Manufacturing artifacts

- `mono-08-package`: updated conventional Gerber/drill/CPL/BOM/native/schematic review package.
- `color-10-package`: same electrical design, with PCBWay UV artwork and positioning files in `UV_PRINT`.
- `color-10/F-color-print.pdf`: exact 1:1, 15.875 mm square page. Also SVG and 2400 × 2400 transparent PNG (3840 dpi). The circle and all openings are registered to native board coordinates.
- F means the circuit back. UV is requested only on F. B is the black/white optical front.
- Full-area color F is white solder mask with dark UV ink background. Request black B mask; supplier must confirm the mixed-side process. PCBWay F silkscreen Gerber is a placement reference for the supplied color replacement, **not an additional white overprint**. B white silkscreen remains conventional.
- User.1–User.4 contain native reference paths for input supply, protected supply, ground and LED cathode respectively. Standard KiCad 3D cannot display the multicolor legend; the UV artwork is authoritative for color.
- Minimum measured colored artwork to mask-opening distance is 0.1536 mm. Optical front minimum is 0.1584 mm. New wordmark edge gap is 0.2241 mm. These are geometric checks, not supplier print-registration approval.

## Release status

Both packages remain **on HOLD for release review**. Retain the original optical-courtyard exception for formal review, verify the mesh-only D1/D2/U1 mechanical models and required independent mechanical evidence, complete the hardware workflow's repeat-build and human Gerber/assembly reviews, reconcile the supplier process and obtain release approval. No new layout bench testing or supplier print proof has occurred. Original BOM/population selections remain unchanged; old lot identifiers/quantities are provenance, not authorization for a new order. No upload, order or supplier message was sent.

See [SUPPLIERS.md](SUPPLIERS.md), [verification.json](verification.json), the individual DRC reports and [review.html](review.html). The shared contact-sheet collection has been extended without replacing sheets 01–09. The routing-attempt ledger retains the earlier partial/rejected native files locally.

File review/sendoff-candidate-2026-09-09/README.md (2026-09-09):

# PulseSensor JST educational board — review candidate

DEVELOPMENT • 2026-09-09 • PulseSilverBookPro

This is a concrete native CAD and manufacturing-export candidate, not an approved production release. No supplier upload or order has been made.

## Design

15.875 mm circular board, 1.6 mm thick. Black solder mask, white silkscreen on both sides. User-facing optical front is KiCad B side; circuit back is KiCad F side. D1, U1, J1 and board outline are unchanged. Twelve passive/diode parts were rearranged and copper rerouted; all original pin-to-net connections and local pad geometries are preserved.

The front uses a photo-reconstructed heart and curved pulsesensor.com wordmark. It is not verified against an original historical artwork master. Back lettering identifies parts and functional groups; dotted guides describe signal connections with deliberate gaps at crossings and text. They are explanatory ink, not a complete depiction of copper or current flow. The solid arrow describes conventional current on the LED cathode-to-resistor branch. Capacitors do not carry steady DC through their dielectric. The full component-function key is in the review page.

## Evidence

All 16 geometry/electrical comparison checks passed: zero unconnected nets, zero schematic parity issues, ERC clear, fixed optics preserved, correct 16-component placement export and unchanged controlled component selections. Native candidate SHA-256: 035ff099151d272f77bd0d54e158b8264b486bc1b7c166ecc0c92d3a766d4b6a.

DRC retains one original D1 optical NPTH / U1 courtyard exception. No new DRC warnings. Measured silk-to-opening clearance is at least 0.1536 mm on F and 0.1584 mm on B. Lettering targets 0.8 mm height and 0.15 mm strokes; full glyph stem metrology and supplier print reconciliation remain to be completed. See VALIDATION.

## Manufacturing review notes / hold points

- This package is on HOLD for release. Existing optical courtyard exception needs the formal review/waiver required by the hardware workflow.
- D1, D2 and U1 source models are mesh-only; verified STEP-capable models and independent mechanical inspection remain outstanding. Rendered component bodies are illustrative and do not constitute mechanical proof.
- Ten populated views are supplied. KiCad renders can display via holes/rings despite native tenting flags. Fabrication mask data and supplier tenting capability govern actual appearance; verify tenting for the 0.30 mm drills.
- Gerbers, drill and CPL share the original auxiliary origin (92.0625, 107.9375). CPL uses the native KiCad side/rotation convention. Confirm the supplier’s assembly interpretation before release.
- The controlled BOM and population matrix are byte-for-byte copies of the original submitted selections. Their original lot quantities/identifiers are provenance, not authorization for a new order. Reconcile the new lot explicitly before ordering.
- Human Gerber and assembly review, required repeat-build evidence, fabricator reconciliation and CEO release approval remain pending. This rearranged layout has not been bench validated.

## Provenance

Submitted source archive SHA-256: 0afda167b52ab0b0251cf22f91fd92fefa5dcf5e74f67b36446e7ec775acf792.
Submitted native PCB SHA-256: b439dcff82c4553731ac35ebcd27276899f8dfbbfcd35f2351d8101497eb4ad4.
Source: PulseSensor-Amped-B-PCBWay-EVT-RC3-R1-FINAL / SOURCE_SUPPORT / PulseSensor-Amped-B-JST.kicad_pcb.

Python crash dialogs were traced to KiCad pcbnew helper shutdown. Final metadata edits used standard Python text parsing and KiCad CLI checks/exports; the crash-prone helpers are no longer used.

Open review.html for the front/back previews and full educational key. The local visual-log/index.html retains the revision trail.

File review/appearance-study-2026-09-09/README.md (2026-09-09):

# PulseSensor front/back appearance study

DEVELOPMENT / generated visual concept only. Not fabrication artwork.

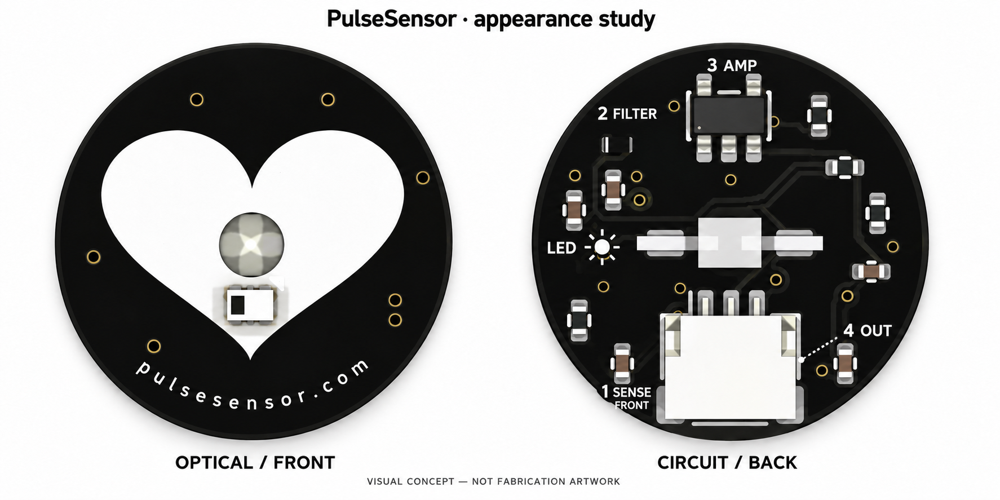
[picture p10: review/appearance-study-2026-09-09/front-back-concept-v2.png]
Paired concept


The visual reference is the verified submitted RC3 B JST board, plus the earlier black/white reconstructed heart-and-website face. The native electrical board has not been modified. The proposed front restores a broad white heart and lowercase `pulsesensor.com` on black. The back uses a numbered functional legend: sensing on the opposite face, filter, amplifier, output. LED illumination is separate.

The original logo audit did not locate original heart/URL silkscreen geometry in the historical DesignSpark/Gerber package. This image therefore represents a best-match visual reconstruction, not an exact original master. Image generation cannot certify exact component geometry, silkscreen registration, clearance, actual-size legibility, or accurate copper connectivity. A native artwork-only implementation and review are still required before manufacture; the generated image must never control fabrication.

Created with the built-in image-generation tool. The first generation had misleading explanatory arrows; the retained second concept removes the signal-chain arrows in favor of numbered stages. The prompts are preserved in `prompts.json`. No supplier message or order was made.

## Expanded teaching concept and native CAD study

The [component teaching concept](component-teaching-concept.png) adds component identities and explanations. Its R1 description is simply “Limits LED current and sets brightness.” The final image-generation specification is in [verbose-prompt.json](verbose-prompt.json).

The [editable KiCad board](native/PulseSensor-JST-Educational-Study.kicad_pcb) now contains actual front and back silkscreen artwork derived from the submitted JST source, rather than artwork existing only in a generated picture. Open the project alongside its supplied libraries and models. [Native render comparison](native/native-review.png).

- The reconstructed heart and curved website are on B.Silkscreen, the optical front. The heart is cut clear of the actual optical aperture, detector pads and existing polarity marking.
- F.Silkscreen, the circuit back, has component references and the functional words that fit: LED, AMP and OUT. Dashed guides follow existing routed signal-net centerlines, with breaks at crossings, pads, bodies and text. Both copper layers are projected onto this explanatory surface; the guides are not a complete wiring diagram. A conventional-current arrow follows the LED cathode branch toward R1.
- A larger [logical circuit drawing](native/logical-schematic.svg) is stored natively on User.1 outside the physical board. It explains the LED current branch, sensor load, coupling/filter network, feedback amplifier, reference divider and supply. This is explanatory CAD geometry, not a replacement ERC-checkable schematic.
- All component placements, pad nets, pad sizes, drills, tracks, vias, board edge and zone descriptors were compared before/after and remain unchanged, including the LED, optical detector and JST connector. The submitted source is untouched. No components were relocated in this iteration.
- Actual KiCad renders use the default green mask display. The intended appearance remains black with white artwork; render color is not a new stackup specification.

**Status: REVISE — native artwork feasibility study.** Native DRC reports zero unconnected items and no silkscreen overlap, pad/mask clipping or edge-clipping warnings. One NPTH/courtyard error also exists in the submitted source. Thirty-three text-height warnings remain: compact back lettering is 0.45 mm, below the project minimum. Full explanatory prose does not fit at readable size with the present placement. Moving parts is permitted by the current design brief, with the LED and optical window fixed, but would require a separately checked routing iteration; this study does not claim that redesign is complete.

The diagnostic gate remains REVISE. No matching native `.kicad_sch` was included in the submitted SOURCE_SUPPORT package, so ERC/parity and the full release/mechanical evidence gate are not satisfied. See [validation summary](native/validation-summary.json) and [source/geometry evidence](native/evidence.json). No fabrication package, supplier upload or order was produced.

Rebuild the native study using `build_native_study.py` with KiCad 10's bundled Python. The script includes exact source paths and hashes are recorded in the evidence. Render the board using `kicad-cli pcb render --side top` / `--side bottom`; export User.1 with `kicad-cli pcb export svg`. The schematic SVG viewport is expanded to include the off-board teaching drawing.

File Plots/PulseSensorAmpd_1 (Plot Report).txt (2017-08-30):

Plot Report
-----------

Report Written:     Wednesday, August 30, 2017
Design Path:        C:\Users\murf\Downloads\PulseSensorAmped Hardware\PulseSensorAmped Hardware\PulseSensorAmpd_1.pcb
Design Title:       
Created:            3/5/2012 9:07:17 PM
Last Saved:         7/27/2016 4:09:04 PM
Editing Time:       6760 min
Units:              thou (precision 0)

Device Settings
===============

Gerber Settings
===============

    Leading zero suppression.
    G01 assumed throughout.
    Line termination <*> <CR> <LF>.
    2.5 format absolute inches.

    Format commands defined in Gerber file.
    Aperture table defined in Gerber file.
    Hardware arcs allowed.

Drill Settings
==============

    Excellon Format 1    Format 3.5 absolute in mm.
    No zero suppression.

Plots Output
============

Gerber Output
=============

C:\Users\murf\Downloads\PulseSensorAmped Hardware\PulseSensorAmped Hardware\Plots\PulseSensorAmpd_1 - Top Solder Mask.gbr

    Layers:
    -------------------
    Top Solder Mask

    D-Code Shape  (thou)
    ----------------------------------------------
    D12    Rectangle 39.40 X 43.30
    D13    Rectangle 39.37 X 59.06  Rotation 90
    D14    Rectangle 39.37 X 42.91
    D15    Rectangle 39.40 X 43.30  Rotation 90
    D16    Rectangle 50.00 X 80.00
    D17    Rectangle 39.37 X 42.91  Rotation 90
    D18    Rectangle 22.00 X 52.00  Rotation 90

Gerber Output
=============

C:\Users\murf\Downloads\PulseSensorAmped Hardware\PulseSensorAmped Hardware\Plots\PulseSensorAmpd_1 - Top Silkscreen.gbr

    Layers:
    ------------------
    Top Silkscreen

    D-Code Shape  (thou)
    -----------------------
    D11    Round 5.00
    D19    Round 8.00
    D70    Round 3.00
    D71    Round 6.00

Gerber Output
=============

C:\Users\murf\Downloads\PulseSensorAmped Hardware\PulseSensorAmped Hardware\Plots\PulseSensorAmpd_1 - Top Copper.gbr

    Layers:
    --------------
    Top Copper

    D-Code Shape  (thou)
    ----------------------------------------------
    D12    Rectangle 39.40 X 43.30
    D13    Rectangle 39.37 X 59.06  Rotation 90
    D14    Rectangle 39.37 X 42.91
    D15    Rectangle 39.40 X 43.30  Rotation 90
    D16    Rectangle 50.00 X 80.00
    D17    Rectangle 39.37 X 42.91  Rotation 90
    D18    Rectangle 22.00 X 52.00  Rotation 90
    D20    Round 87.00
    D21    Round 60.00
    D22    Round 48.00
    D23    Round 15.00
    D24    Round 25.00

Gerber Output
=============

C:\Users\murf\Downloads\PulseSensorAmped Hardware\PulseSensorAmped Hardware\Plots\PulseSensorAmpd_1 - Top Copper (Resist).gbr

    Layers:
    --------------
    Top Copper

    D-Code Shape  (thou)
    ----------------------------------------------
    D25    Round 97.00
    D26    Round 70.00
    D27    Rectangle 49.40 X 53.30
    D28    Rectangle 49.37 X 69.06  Rotation 90
    D29    Rectangle 49.37 X 52.91
    D72    Rectangle 49.40 X 53.30  Rotation 90
    D73    Rectangle 60.00 X 90.00
    D74    Rectangle 49.37 X 52.91  Rotation 90
    D75    Rectangle 32.00 X 62.00  Rotation 90

Gerber Output
=============

C:\Users\murf\Downloads\PulseSensorAmped Hardware\PulseSensorAmped Hardware\Plots\PulseSensorAmpd_1 - Bottom Copper.gbr

    Layers:
    -----------------
    Bottom Copper

    D-Code Shape  (thou)
    -----------------------
    D20    Round 87.00
    D21    Round 60.00
    D22    Round 48.00
    D23    Round 15.00
    D24    Round 25.00

Gerber Output
=============

C:\Users\murf\Downloads\PulseSensorAmped Hardware\PulseSensorAmped Hardware\Plots\PulseSensorAmpd_1 - Bottom Copper (Resist).gbr

    Layers:
    -----------------
    Bottom Copper

    D-Code Shape  (thou)
    -----------------------
    D25    Round 97.00
    D26    Round 70.00

NC Drill Output
===============

C:\Users\murf\Downloads\PulseSensorAmped Hardware\PulseSensorAmped Hardware\Plots\PulseSensorAmpd_1 - Drill Data - [Through Hole].drl

    Output:
    ---------------------------
    Plated Round Drill Holes
    Plated Slots
    Plated Board Outlines

    Tool  Size         Count   ID
    ------------------------------------
    T001  000.02400 in 9     G
    T002  000.03500 in 3     A
    T003  000.08500 in 1     F
    ------------------------------------
    Total              13
    ------------------------------------

C:\Users\murf\Downloads\PulseSensorAmped Hardware\PulseSensorAmped Hardware\Plots\PulseSensorAmpd_1 - Drill Data - [Through Hole] (Unplated).drl

    Output:
    -----------------------------
    Unplated Round Drill Holes
    Unplated Slots
    Unplated Board Outlines

    Tool  Size         Count   ID
    ------------------------------------
    T001  000.02500 in 1
    ------------------------------------
    Total              1
    ------------------------------------

Gerber Output
=============

C:\Users\murf\Downloads\PulseSensorAmped Hardware\PulseSensorAmped Hardware\Plots\PulseSensorAmpd_1 - Drill Ident Drawing - [Through Hole].gbr

    Layers:
    ------------------
    [Through Hole]

Drill Ident Drawing
===================

    Drill Plated Size Shape ID
    -----------------------------------
    35    Y      100  Round A
    85    Y      100  Round F
    24    Y      100  Round G

    D-Code Shape  (thou)
    -----------------------
    D10    Round 100.00
    D11    Round 5.00

Gerber Output
=============

C:\Users\murf\Downloads\PulseSensorAmped Hardware\PulseSensorAmped Hardware\Plots\PulseSensorAmpd_1 - Outline.gbr

    Layers:
    ------------------
    Board Outlines

    D-Code Shape  (thou)
    -----------------------
    D11    Round 5.00

End Of Report.

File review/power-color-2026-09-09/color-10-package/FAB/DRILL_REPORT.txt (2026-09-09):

Drill report for PulseSensor-JST-Educational.kicad_pcb
Created on 2026-09-09T16:58:03

Copper Layer Stackup:
    =============================================================
    L1 :  F.Cu                      front
    L2 :  B.Cu                      back

Drill file 'PulseSensor-JST-Educational-PTH.drl' contains
    plated through holes:
    =============================================================
    T1  0.300mm  0.0118"  (18 holes))

    Total plated holes count 18

Drill file 'PulseSensor-JST-Educational-NPTH.drl' contains
    unplated through holes:
    =============================================================
    T1  2.159mm  0.0850"  (1 hole)

    Total unplated holes count 1

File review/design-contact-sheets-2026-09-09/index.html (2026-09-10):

# PulseSensor visual contact sheets

Original sheets preserved; new revisions appended. Click a sheet to inspect at full resolution.

Current monochrome and color review · Exact source index · Every routing attempt

## Sheet 01



## Sheet 02



## Sheet 03



## Sheet 04



## Sheet 05



## Sheet 06



## Sheet 07



## Sheet 08



## Sheet 09



## Sheet 10

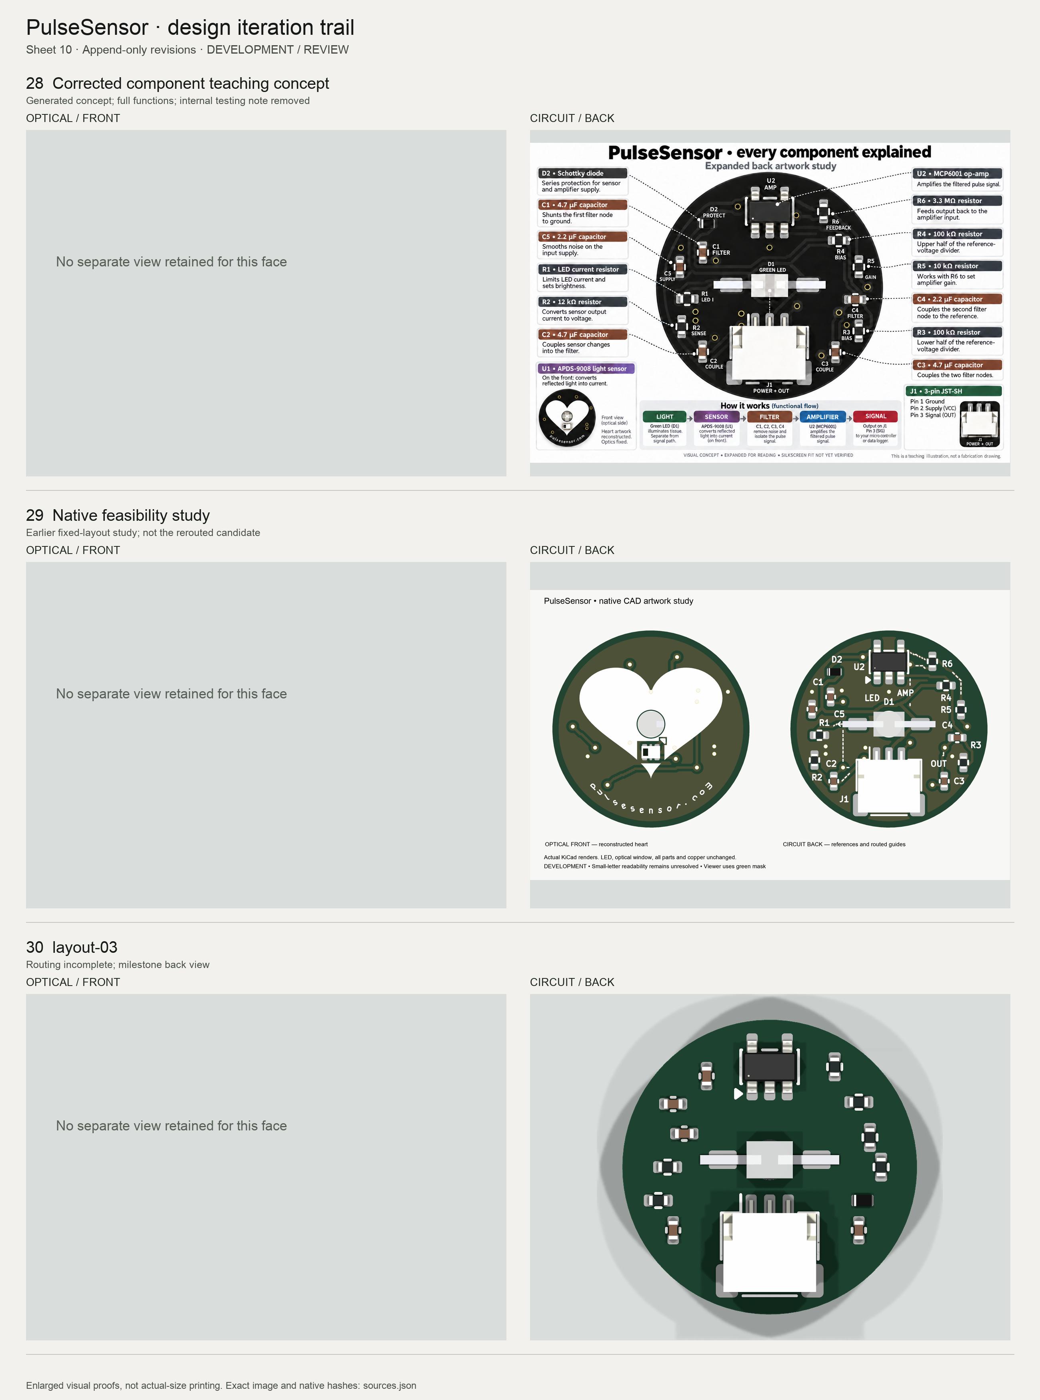
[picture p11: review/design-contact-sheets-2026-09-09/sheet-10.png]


## Sheet 11

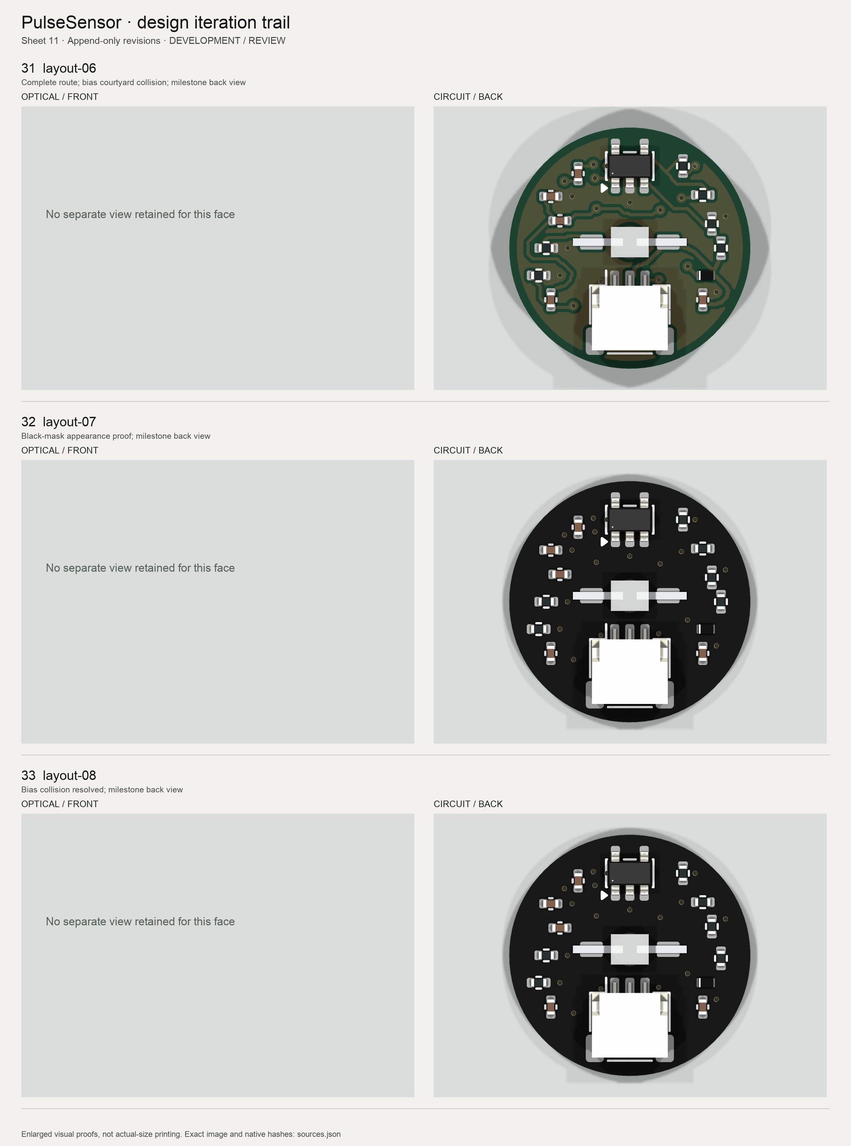
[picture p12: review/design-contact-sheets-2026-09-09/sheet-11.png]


## Sheet 12

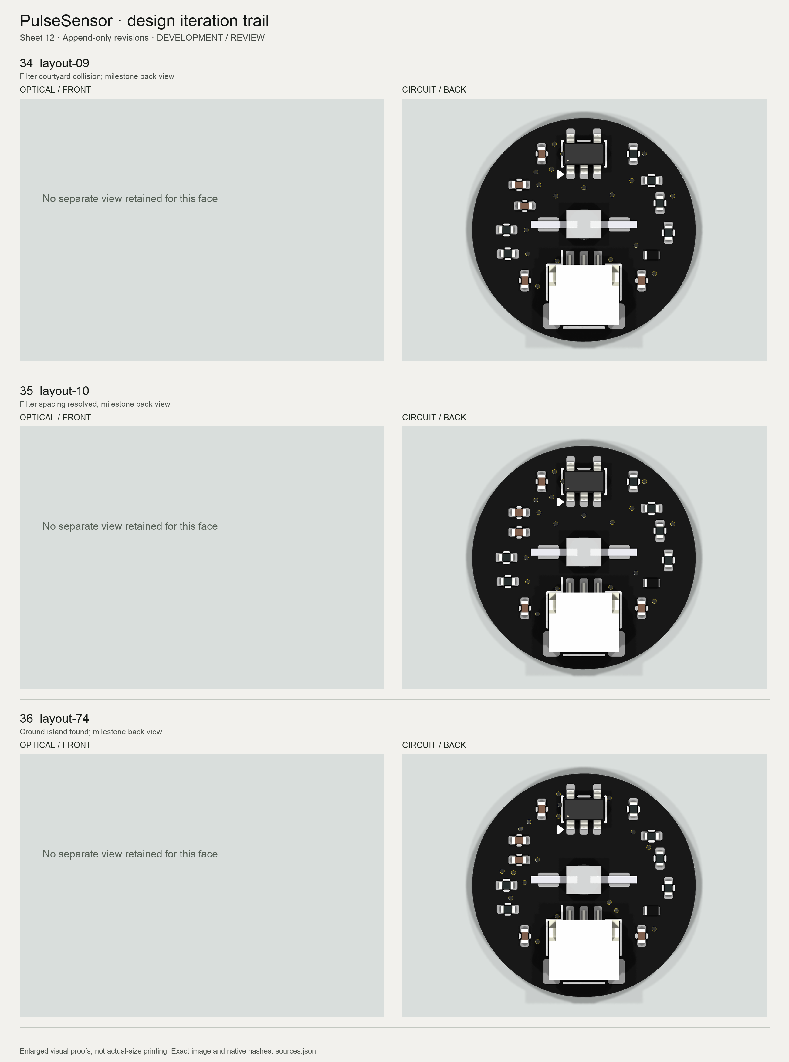
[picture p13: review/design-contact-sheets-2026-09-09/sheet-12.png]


## Sheet 13

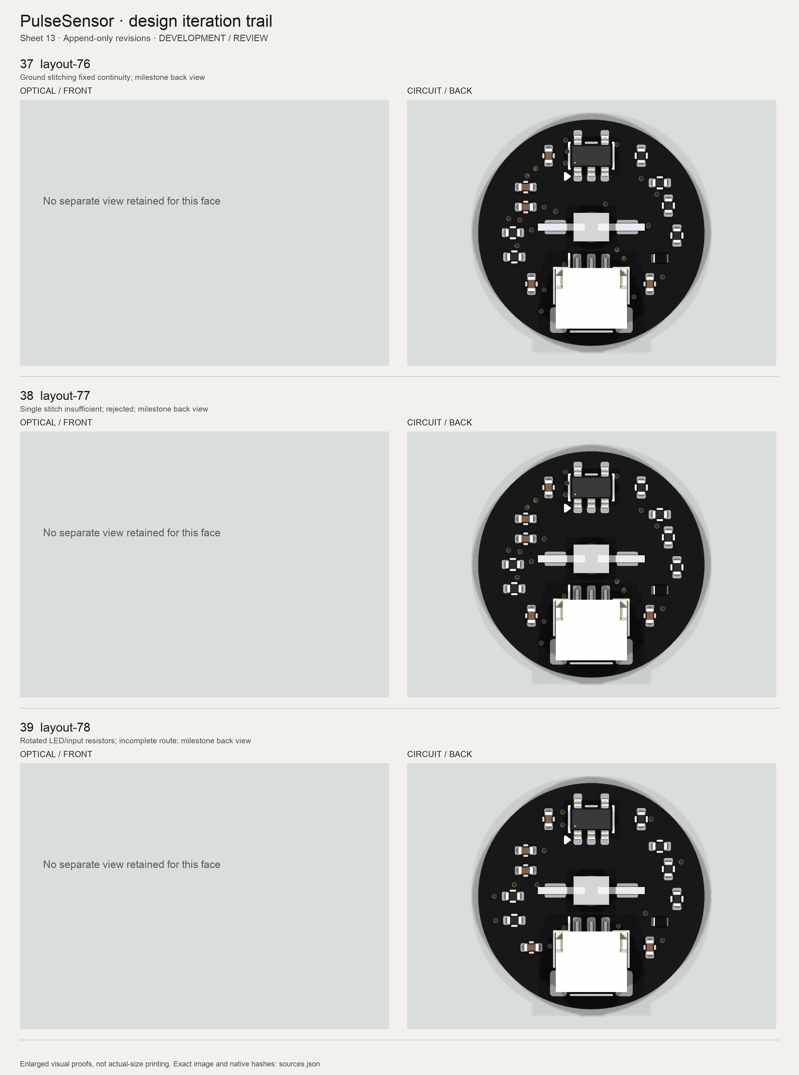
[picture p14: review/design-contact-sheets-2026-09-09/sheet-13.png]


## Sheet 14

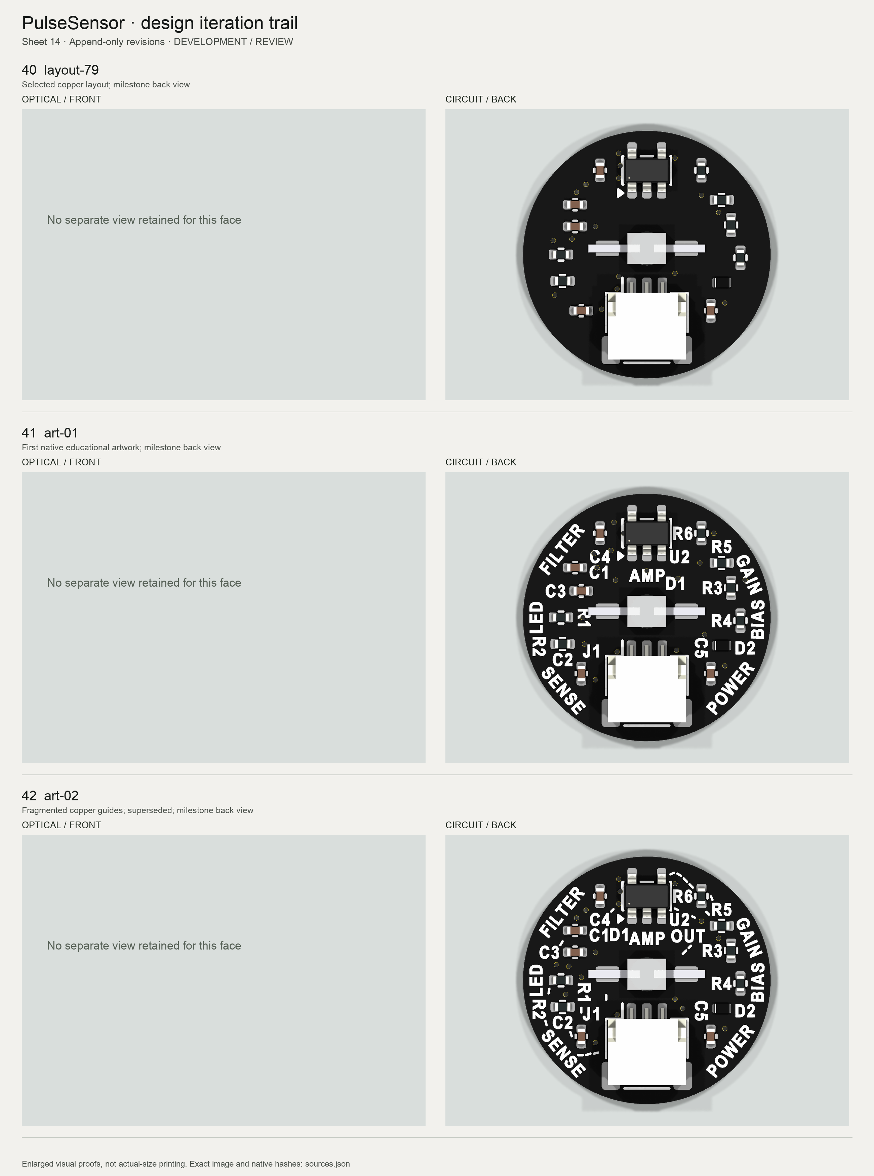
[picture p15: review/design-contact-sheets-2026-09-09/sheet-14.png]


## Sheet 15

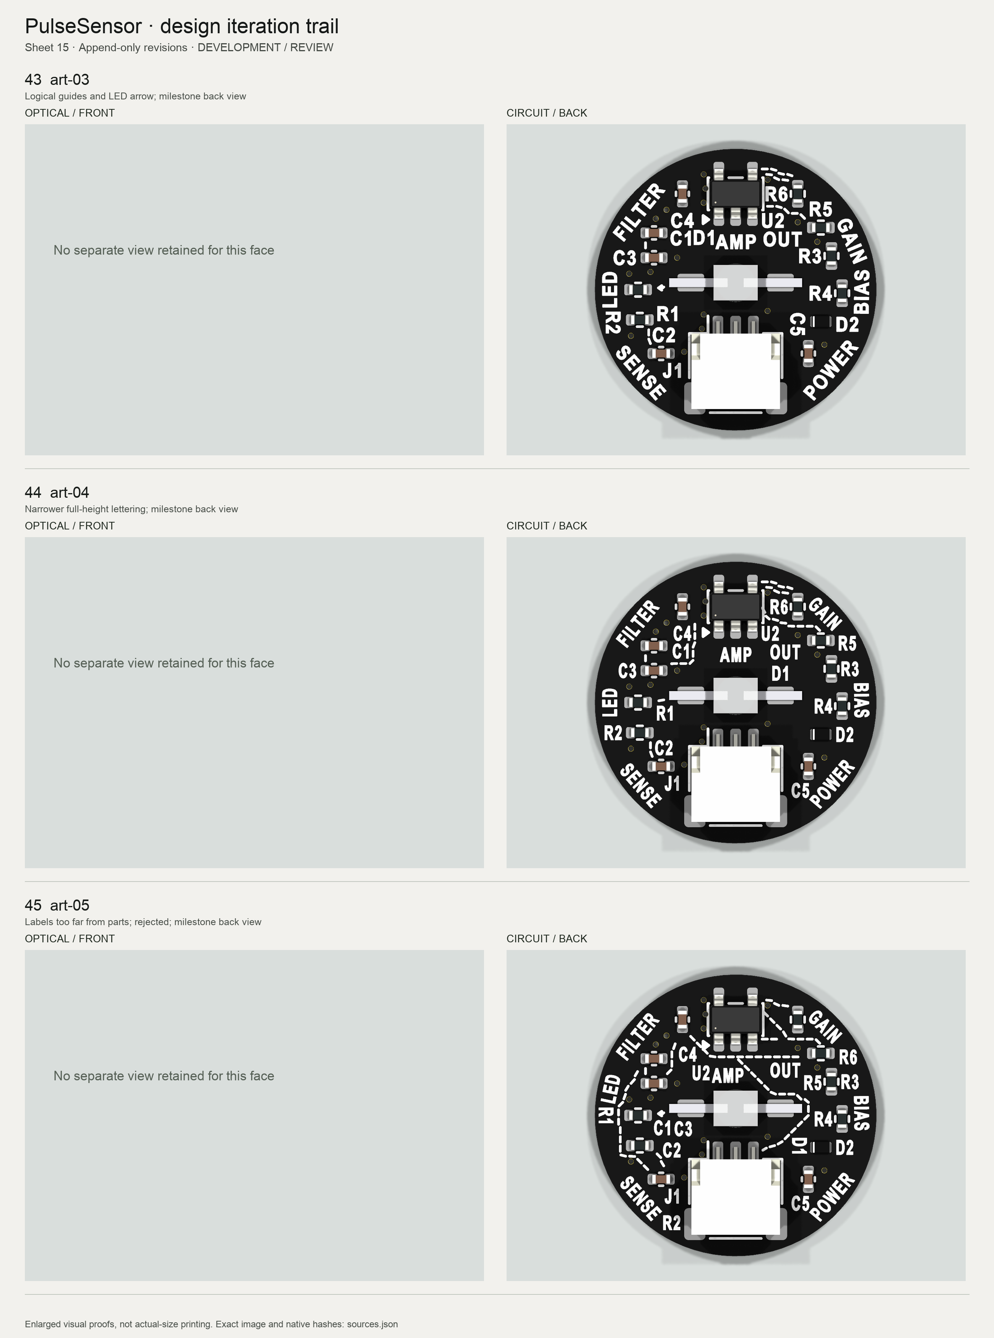
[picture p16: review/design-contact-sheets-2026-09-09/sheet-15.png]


## Sheet 16

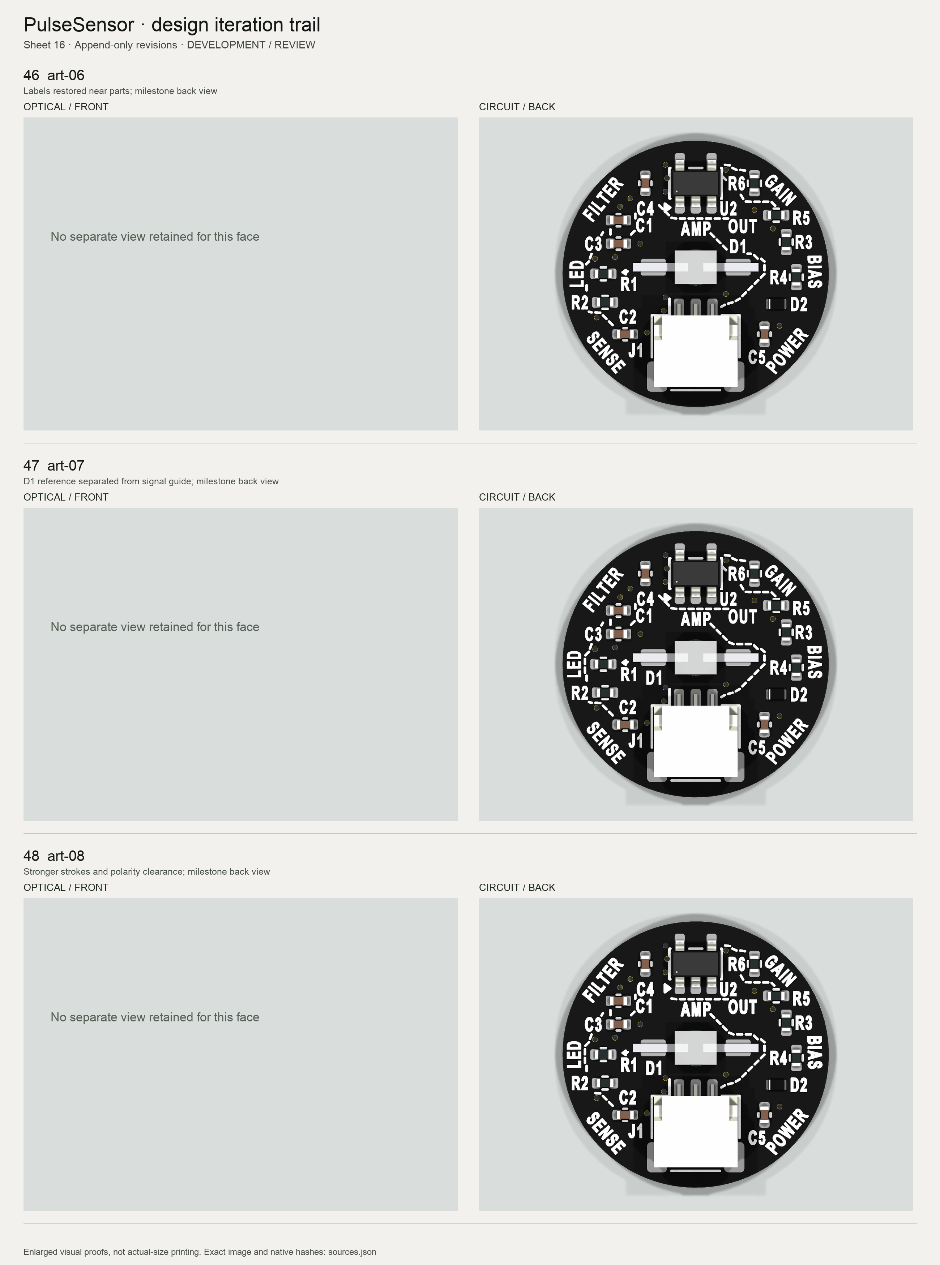
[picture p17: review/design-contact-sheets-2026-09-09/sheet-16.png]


## Sheet 17

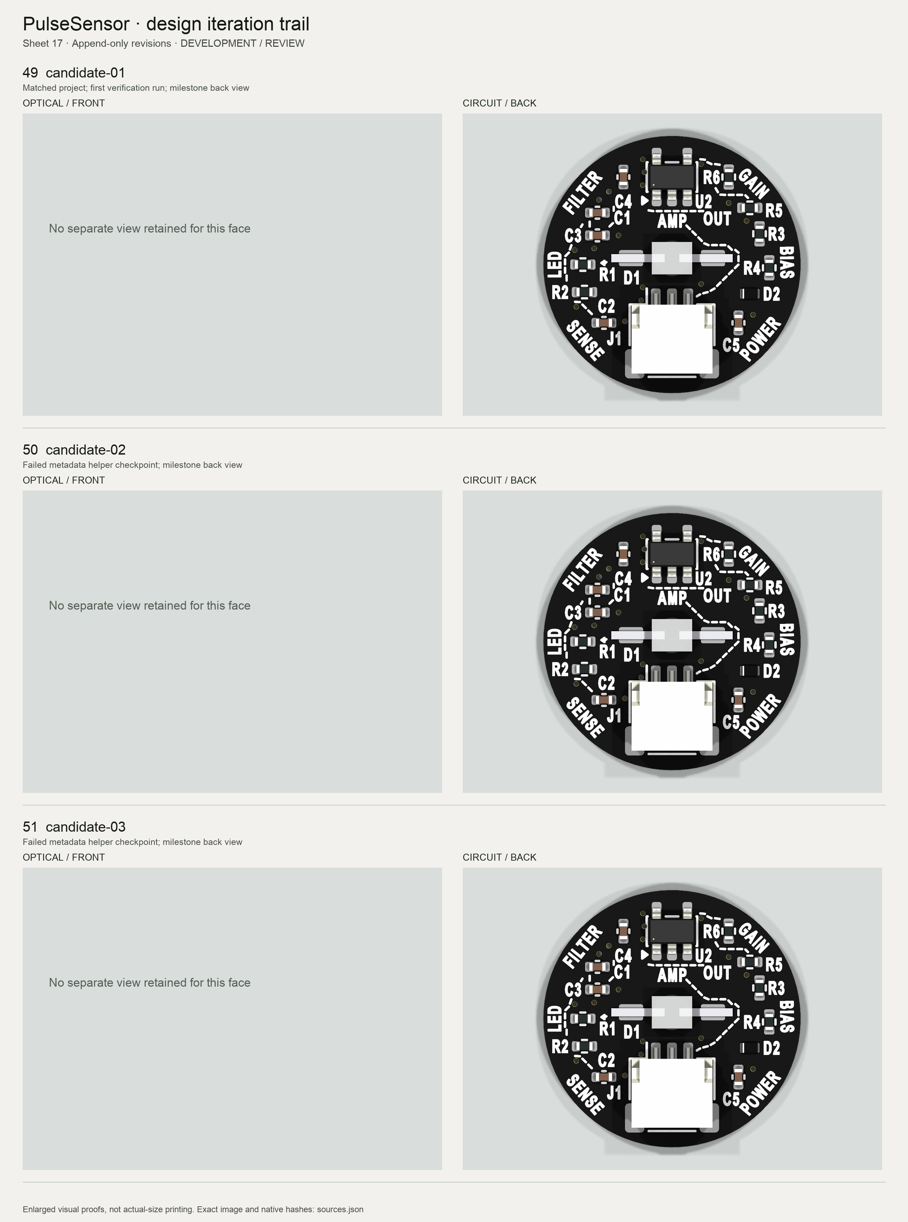
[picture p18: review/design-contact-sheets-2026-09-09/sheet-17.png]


## Sheet 18

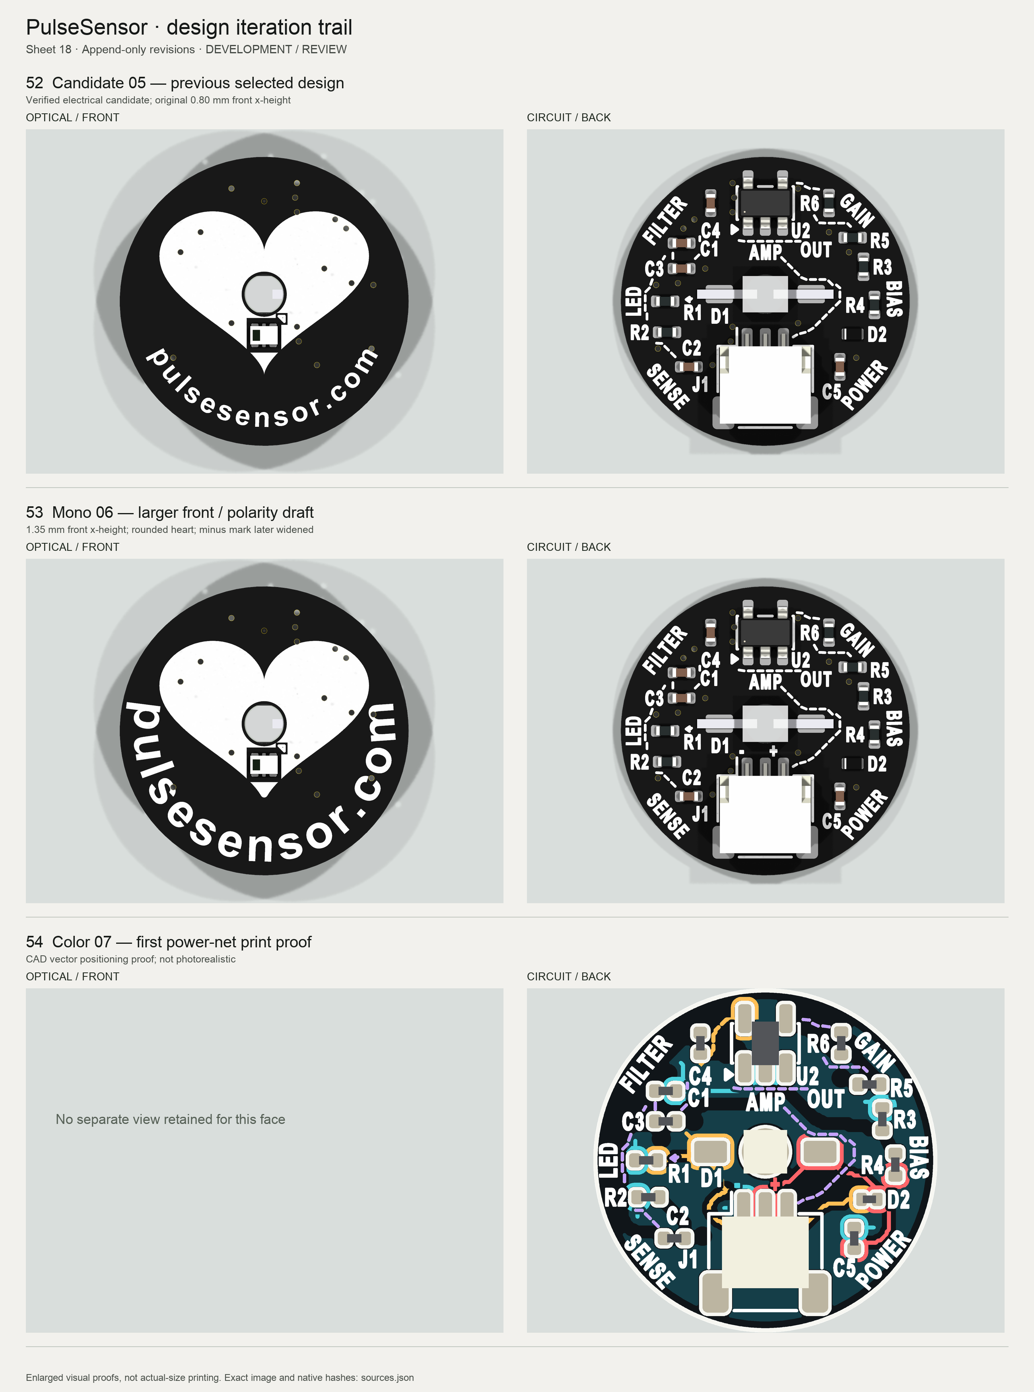
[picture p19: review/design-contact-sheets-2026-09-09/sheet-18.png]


## Sheet 19

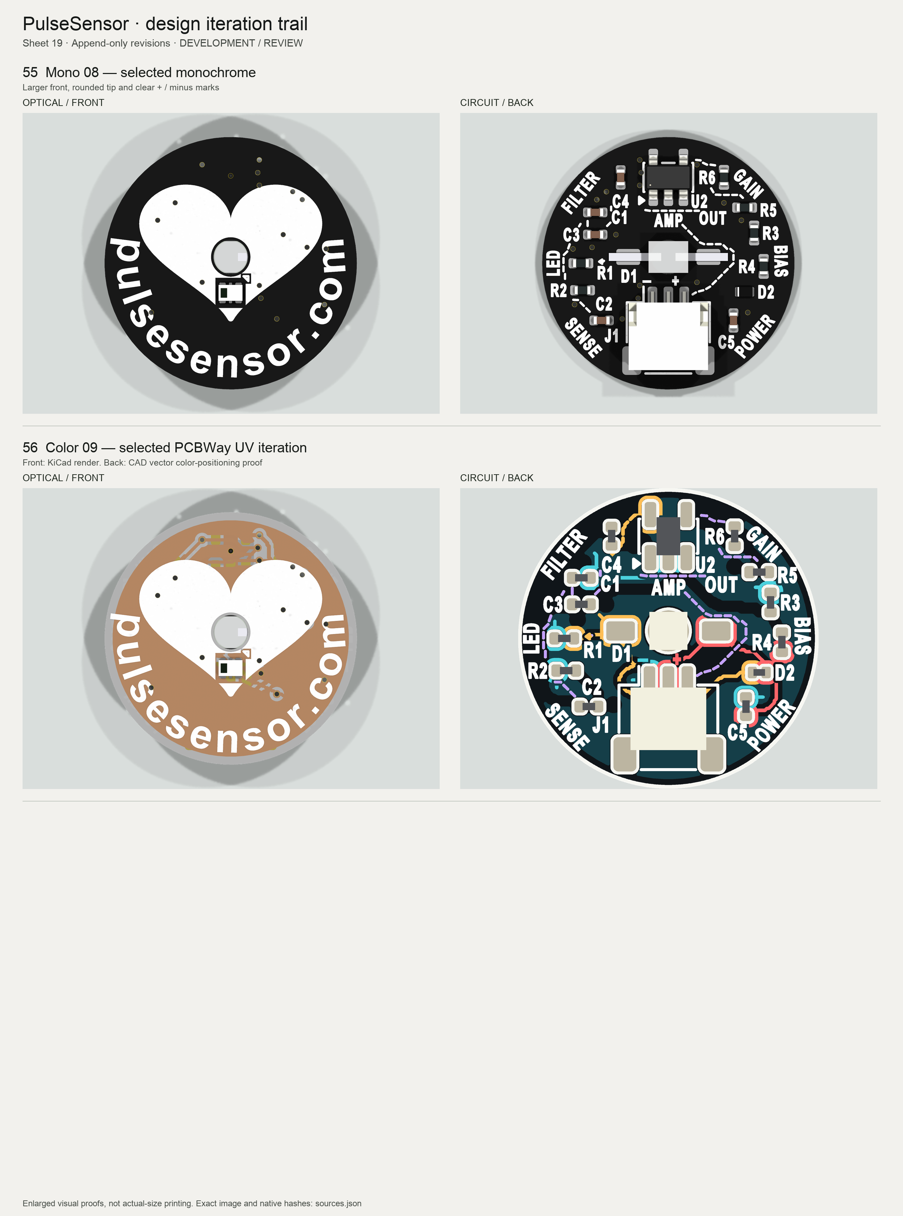
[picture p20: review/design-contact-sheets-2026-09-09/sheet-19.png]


## Sheet 20 — current selected candidates

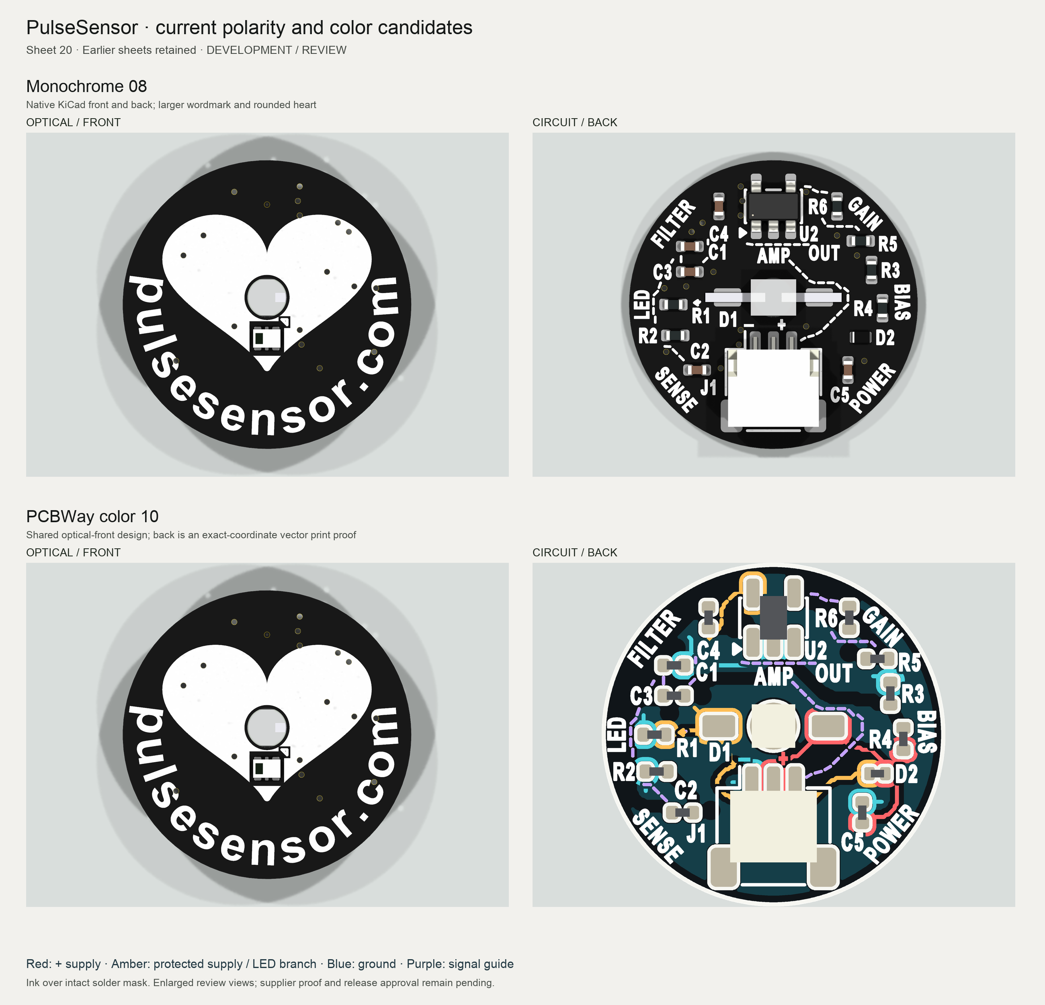
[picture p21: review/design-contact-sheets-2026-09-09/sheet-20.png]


## Sheet 21 — hardware postcard + BOM

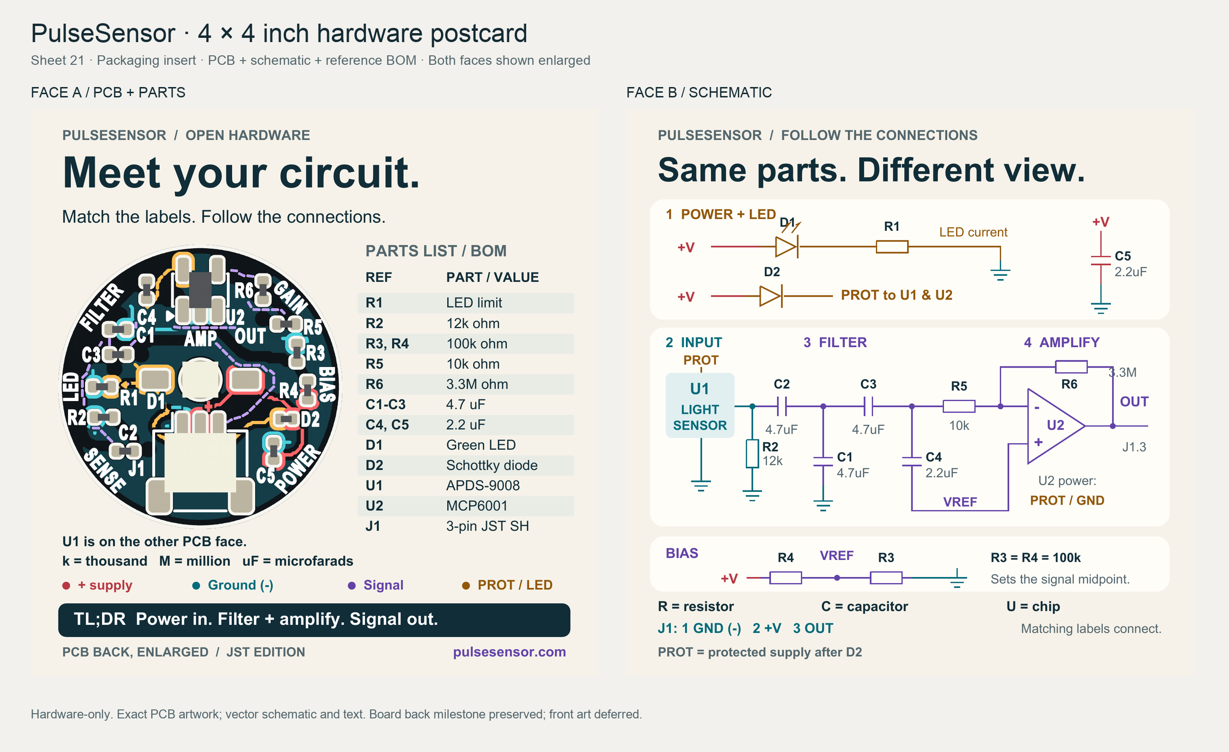
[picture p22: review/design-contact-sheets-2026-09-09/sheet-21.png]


## Sheet 22 — complete schematic companion postcard

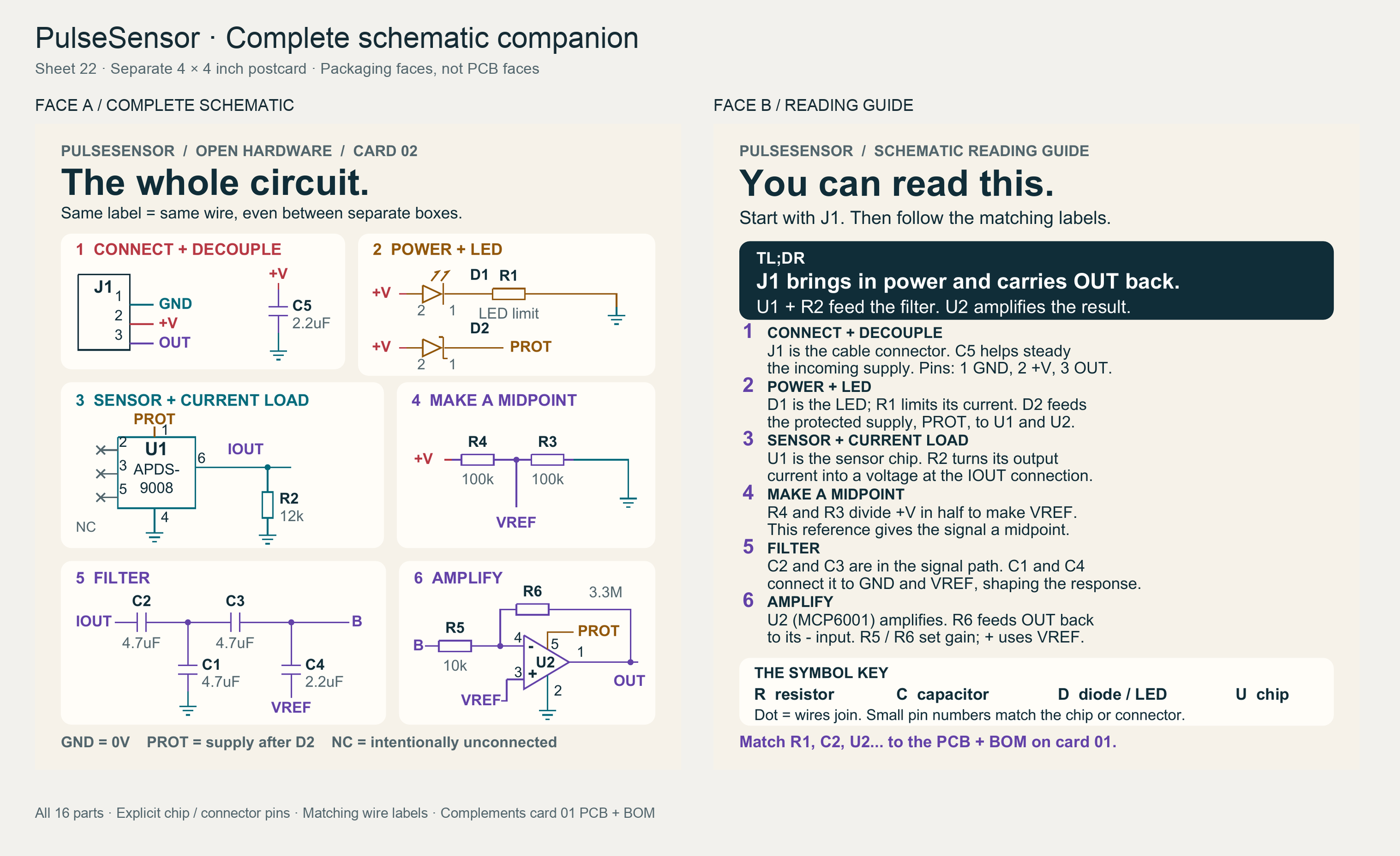
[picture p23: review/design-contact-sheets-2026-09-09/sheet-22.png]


## Sheet 23 — puzzle module background

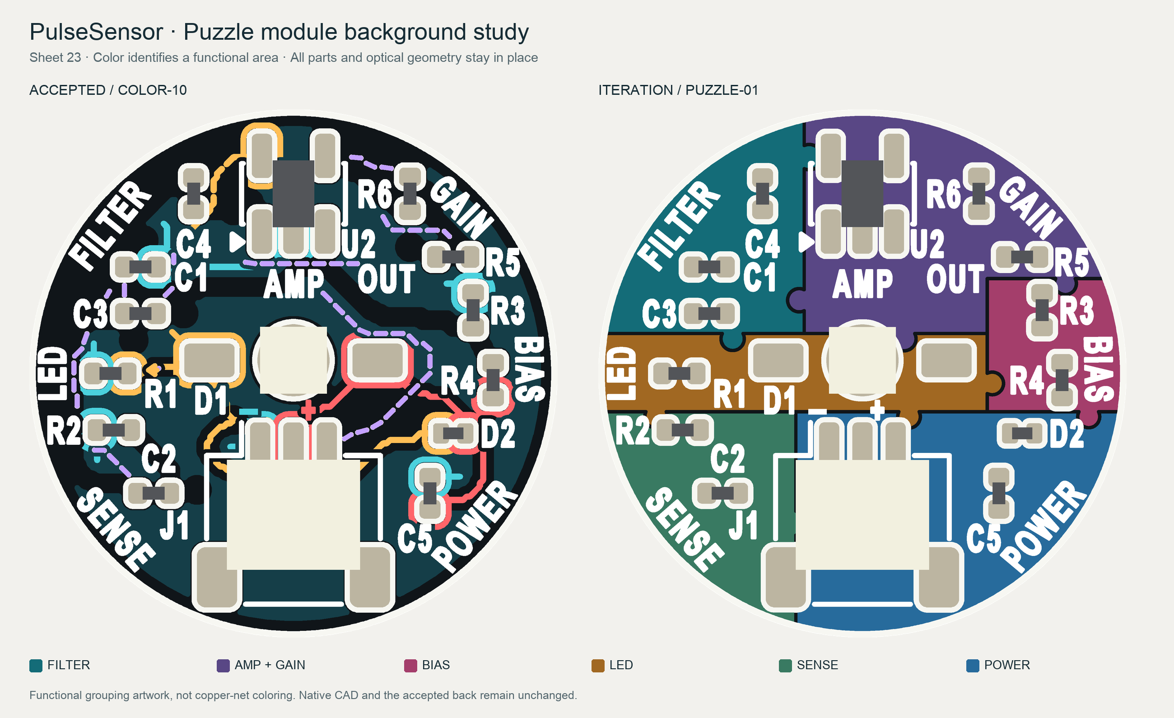
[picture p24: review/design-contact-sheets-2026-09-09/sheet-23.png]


## Sheet 24 — dotted module outlines



## Sheet 25 — full-color retail schematic card



## Sheet 26 — PulseSensor brand unification



## Sheet 27 — PulseSensor WebSerial palette



## Sheet 28 — PulseSensor WebSerial palette



## Sheet 29 — PulseSensor WebSerial palette



## Sheet 30 — Six-color brand trial



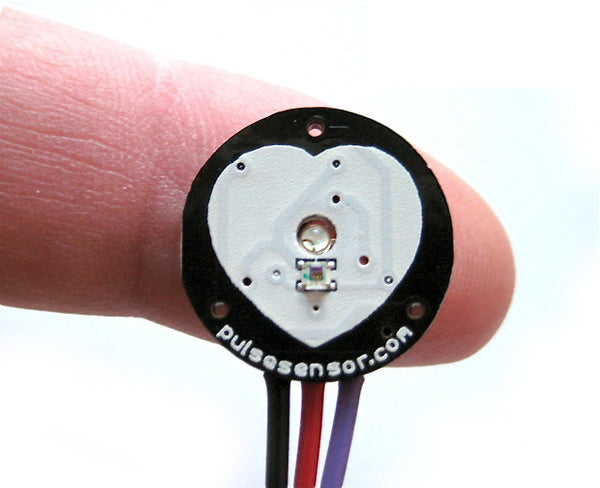
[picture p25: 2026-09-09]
review/power-color-2026-09-09/references/optical-front.jpg

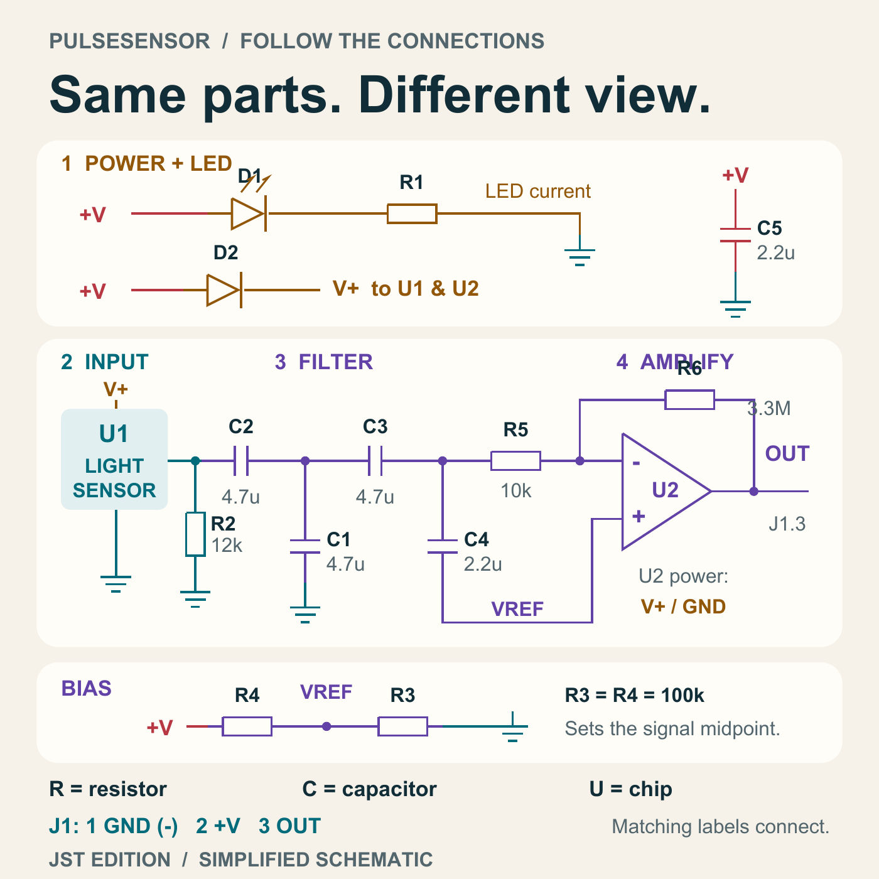
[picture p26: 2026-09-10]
review/postcard-insert-2026-09-10/iterations/01-hardware-map/card-2.png

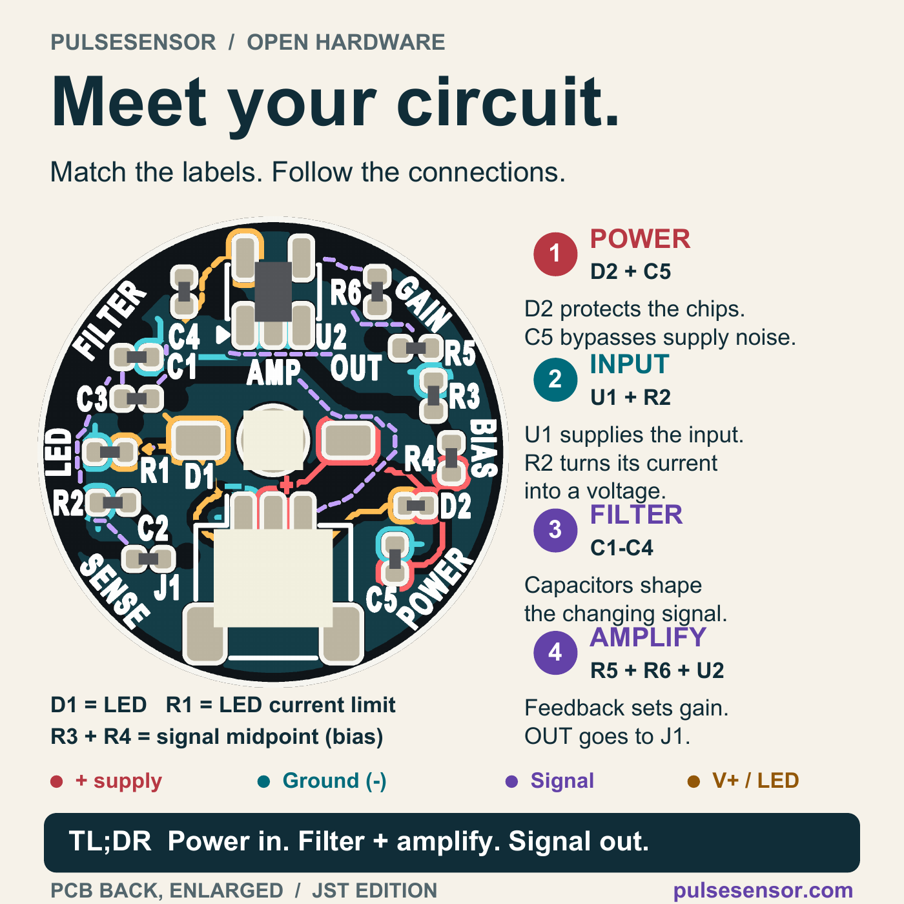
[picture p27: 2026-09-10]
review/postcard-insert-2026-09-10/iterations/01-hardware-map/card-1.png

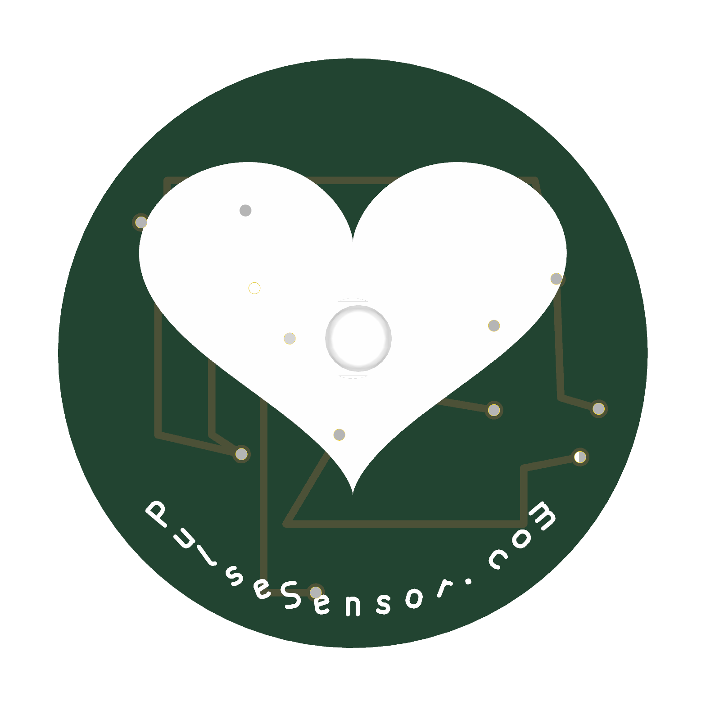
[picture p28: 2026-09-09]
review/design-contact-sheets-2026-09-09/rendered-missing-views/06-front.png

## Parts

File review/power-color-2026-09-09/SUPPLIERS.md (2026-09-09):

# Color printing supplier comparison

Checked 2026-09-09. Public documentation only; no supplier contacted, files uploaded, price quoted or order placed.

| Supplier | Verified capability | Consequence for this design |
| --- | --- | --- |
| PCBWay | Matte UV multicolor printing; separate print image and positioning reference accepted alongside Gerbers. Full-area printing uses white mask on that side. | Primary artwork package uses a dark UV background over white F mask; black B optical mask is requested and needs quote reconciliation. Keep the 1:1 PDF/PNG and positioning proof together. |
| JLCPCB | Multicolor service, with current documentation requiring EasyEDA Pro color production files. Listed constraints include white mask, 2/4 layers, 1 oz copper and ENIG. Assembly requires customer panel edge rails. | Concept is visually portable, but this KiCad package is not a JLC color-order file. Requires a separately verified EasyEDA/panel export and finish/mask reconciliation. |
| MacroFab | Official documentation lists selectable silkscreen colors. No official full-color UV/CMYK offering was found. | Do not assume multiple simultaneous colors are available; treat full-color as unconfirmed and retain the monochrome candidate. |

Primary sources:

- [PCBWay UV color-printing instructions](https://www.pcbway.com/blog/News/Unlock_Color_PCB_Printing_with_PCBWay_0939d559.html)
- [PCBWay color-printing mask policy](https://www.pcbway.com/blog/PCB_Manufacturing_Information/How_should_the_solder_mask_color_be_chosen_for_color_printed_PCBs_65c898fe.html)
- [JLCPCB color design/export instructions](https://jlcpcb.com/help/article/how-to-design-multi-color-silkscreen-using-easyeda)
- [MacroFab PCB specifications](https://help.macrofab.com/knowledge/pcb-specifications-and-drc)
- [MacroFab specification PDF](https://help.macrofab.com/hubfs/PCB_Specifications.pdf)

PCBWay's standard legend guidance specifies 0.8 mm text height and 0.15 mm stroke. We retained these conservative design targets rather than assuming UV printing permits smaller marks. Color registration and minimum isolated UV features require supplier confirmation; RGB screen previews are not contractual printed-color matches.

[PCBWay legend guidance](https://www.pcbway.com/helpcenter/design_instruction/How_to_make_my_silkscreen_clear_and_beautiful_on_PCB__.html)

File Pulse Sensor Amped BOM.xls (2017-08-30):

Component | BoardRef | Value | Desc | Qty | Mfr | Package | Datasheet Link
APDS-9008 | U1 |  | Sensor | 1 | Avago | SMT | http://www.avagotech.com/docs/AV02-1169EN
MCP6001 | U2 |  | Op Amp |  | Microchip |  | http://ww1.microchip.com/downloads/en/devicedoc/21733j.pdf
RevMntLED | D1 |  | Reverse Mount LED | 1 | Kingbright | Reverse Mount SMT | http://www.kingbrightusa.com/images/catalog/SPEC/AM2520ZGC09.pdf
Schottkey | D2 |  | Powerline Diode |  | Bourns | SMT0603 | http://www.bourns.com/data/global/pdfs/SBCD0603_1005.pdf
CAP 4.7uF 0603 | C1,C2,C3 | 4.7uF | Capacitor, Surface Mount Multi-Layer Ceramic | 1 | Various | SMT0603
CAP 0.1uF 0603 | C4,C5 | 2.2uF | Capacitor, Surface Mount Multi-Layer Ceramic | 1 | Various | SMT0603
R 470 0603 | R1 | 470K | SMT Resistor | 1 | Various | SMT0603
R 100 0603 | R2 | 12K | SMT Resistor | 1 | Various | SMT0603
R 13K 0603 | R3,R4 | 100K | SMT Resistor | 2 | Various | SMT0603
R 13K 0603 | R5 | 10K | SMT Resistor | 1 | Various | SMT0603
R 13K 0603 | R6 | 3.3M | SMT Resistor | 1 | Various | SMT0603

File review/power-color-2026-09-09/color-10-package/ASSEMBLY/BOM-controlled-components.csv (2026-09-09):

Lot Quantity (10 PCBAs) | Per-PCBA Quantity | References | Board IDs | Value | Tolerance | Package | Mounting / Type | Manufacturer | Manufacturer Part Number | Distributor | Distributor Part Number | DNP / NC Handling | Sourcing Policy | Substitution
30 | 3 | C1 C2 C3 | B-01 B-02 B-03 B-04 B-05 B-06 B-07 B-08 B-09 B-10 | 4.7uF | 20% | C_0402_1005Metric | SMT | Murata | GRM155R60J475ME47D | PCBWay or authorized distributor | Source exact MPN | POPULATE; no DNP/NC BOM lines | Source exact listed MPN | NO - written WFE approval required
20 | 2 | C4 C5 | B-01 B-02 B-03 B-04 B-05 B-06 B-07 B-08 B-09 B-10 | 2.2uF | 10% | C_0402_1005Metric | SMT | Murata | GRM155R61A225KE01D | PCBWay or authorized distributor | Source exact MPN | POPULATE; no DNP/NC BOM lines | Source exact listed MPN | NO - written WFE approval required
10 | 1 | D1 | B-01 B-02 B-03 B-04 B-05 B-06 B-07 B-08 B-09 B-10 | AM2520ZGC09 | N/A | AM2520ZGC09_ReverseMount_OriginalAperture | SMT | Kingbright | AM2520ZGC09 | PCBWay or authorized distributor | Source exact MPN | POPULATE; no DNP/NC BOM lines | Source exact listed MPN | NO - written WFE approval required
10 | 1 | D2 | B-01 B-02 B-03 B-04 B-05 B-06 B-07 B-08 B-09 B-10 | NSR05F40NXT5G | N/A | NSR05F40NXT5G_DSN2 | SMT | onsemi | NSR05F40NXT5G | PCBWay or authorized distributor | Source exact MPN | POPULATE; no DNP/NC BOM lines | Source exact listed MPN | NO - written WFE approval required
10 | 1 | J1 | B-01 B-02 B-03 B-04 B-05 B-06 B-07 B-08 B-09 B-10 | SM03B-SRSS-TB | N/A | JST_SH_SM03B-SRSS-TB_1x03-1MP_P1.00mm_Horizontal | SMT | JST | SM03B-SRSS-TB | PCBWay or authorized distributor | Source exact MPN | POPULATE; no DNP/NC BOM lines | Source exact listed MPN | NO - written WFE approval required
10 | 1 | R2 | B-01 B-02 B-03 B-04 B-05 B-06 B-07 B-08 B-09 B-10 | 12K | 1% | R_0402_1005Metric | SMT | Yageo | RC0402FR-0712KL | PCBWay or authorized distributor | Source exact MPN | POPULATE; no DNP/NC BOM lines | Source exact listed MPN | NO - written WFE approval required
20 | 2 | R3 R4 | B-01 B-02 B-03 B-04 B-05 B-06 B-07 B-08 B-09 B-10 | 100K | 1% | R_0402_1005Metric | SMT | Yageo | RC0402FR-07100KL | PCBWay or authorized distributor | Source exact MPN | POPULATE; no DNP/NC BOM lines | Source exact listed MPN | NO - written WFE approval required
10 | 1 | R5 | B-01 B-02 B-03 B-04 B-05 B-06 B-07 B-08 B-09 B-10 | 10K | 1% | R_0402_1005Metric | SMT | Yageo | RC0402FR-0710KL | PCBWay or authorized distributor | Source exact MPN | POPULATE; no DNP/NC BOM lines | Source exact listed MPN | NO - written WFE approval required
10 | 1 | R6 | B-01 B-02 B-03 B-04 B-05 B-06 B-07 B-08 B-09 B-10 | 3.3M | 1% | R_0402_1005Metric | SMT | Yageo | RC0402FR-073M3L | PCBWay or authorized distributor | Source exact MPN | POPULATE; no DNP/NC BOM lines | Source exact listed MPN | NO - written WFE approval required
10 | 1 | U1 | B-01 B-02 B-03 B-04 B-05 B-06 B-07 B-08 B-09 B-10 | APDS-9008-020 | N/A | APDS-9008-020 | SMT | Broadcom | APDS-9008-020 | PCBWay or authorized distributor | Source exact MPN | POPULATE; no DNP/NC BOM lines | Source exact listed MPN | NO - written WFE approval required
10 | 1 | U2 | B-01 B-02 B-03 B-04 B-05 B-06 B-07 B-08 B-09 B-10 | MCP6001T-I/OT | N/A | SOT-23-5 | SMT | Microchip | MCP6001T-I/OT | PCBWay or authorized distributor | Source exact MPN | POPULATE; no DNP/NC BOM lines | Source exact listed MPN | NO - written WFE approval required
1 | 1 | R1 | B-01 | 470 ohm | 1% | 0402 / 1005 metric | SMT | Yageo | RC0402FR-07470RL | PCBWay or authorized distributor | Source exact MPN | POPULATE R1 on every listed board; R1 is never DNP | Populate only on the listed board IDs; use the controlled R1 matrix and common CPL | No substitution without written WFE approval
2 | 1 | R1 | B-02 B-03 | 1.0 kohm | 1% | 0402 / 1005 metric | SMT | Yageo | RC0402FR-071KL | PCBWay or authorized distributor | Source exact MPN | POPULATE R1 on every listed board; R1 is never DNP | Populate only on the listed board IDs; use the controlled R1 matrix and common CPL | No substitution without written WFE approval
2 | 1 | R1 | B-04 B-05 | 1.5 kohm | 1% | 0402 / 1005 metric | SMT | Yageo | RC0402FR-071K5L | PCBWay or authorized distributor | Source exact MPN | POPULATE R1 on every listed board; R1 is never DNP | Populate only on the listed board IDs; use the controlled R1 matrix and common CPL | No substitution without written WFE approval
1 | 1 | R1 | B-06 | 2.2 kohm | 1% | 0402 / 1005 metric | SMT | Yageo | RC0402FR-072K2L | PCBWay or authorized distributor | Source exact MPN | POPULATE R1 on every listed board; R1 is never DNP | Populate only on the listed board IDs; use the controlled R1 matrix and common CPL | No substitution without written WFE approval
2 | 1 | R1 | B-07 B-08 | 2.7 kohm | 1% | 0402 / 1005 metric | SMT | Yageo | RC0402FR-072K7L | PCBWay or authorized distributor | Source exact MPN | POPULATE R1 on every listed board; R1 is never DNP | Populate only on the listed board IDs; use the controlled R1 matrix and common CPL | No substitution without written WFE approval
1 | 1 | R1 | B-09 | 3.3 kohm | 1% | 0402 / 1005 metric | SMT | Yageo | RC0402FR-073K3L | PCBWay or authorized distributor | Source exact MPN | POPULATE R1 on every listed board; R1 is never DNP | Populate only on the listed board IDs; use the controlled R1 matrix and common CPL | No substitution without written WFE approval
1 | 1 | R1 | B-10 | 4.7 kohm | 1% | 0402 / 1005 metric | SMT | Yageo | RC0402FR-074K7L | PCBWay or authorized distributor | Source exact MPN | POPULATE R1 on every listed board; R1 is never DNP | Populate only on the listed board IDs; use the controlled R1 matrix and common CPL | No substitution without written WFE approval

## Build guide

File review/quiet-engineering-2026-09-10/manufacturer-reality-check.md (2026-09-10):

# Manufacturer reality check

Reviewed 2026-09-10. Classification: DEVELOPMENT feasibility research. This is a review of official published information, not vendor correspondence, a quotation or approval of our actual files. No supplier was contacted and no order was placed.

## Verdict

PCBWay and JLCPCB advertise a process capable of multicolor graphic areas like these. That does not establish exact matching of our RGB swatches. MacroFab advertises custom colors, but its published capabilities do not explicitly confirm six-color image printing on one PCB face. My practical first-proof recommendation is PCBWay; JLCPCB is an alternative with more file-preparation constraints.

## PCBWay — full-color process confirmed

Offers multicolor UV printing, matte by default, with a white solder-mask base on a fully printed side. Requires artwork, positioning reference and Gerbers together. The guidance supports common image/PDF formats, says normal prints survive SMT reflow, and requires avoiding pad openings. It also distinguishes the less durable printed ink from the mask beneath it. [Official color-printing guide](https://www.pcbway.com/blog/News/Unlock_Color_PCB_Printing_with_PCBWay_0939d559.html).

For this design: seek a matte sample, explicit confirmation that the opposite black optical mask stays unchanged, and approval of our small lettering/dotted boundaries. No exact color tolerance is published in the cited guide.

## JLCPCB — full-color process confirmed, workflow constrained

Requires EasyEDA Pro color-production exports. Listed options include white mask, 2/4 layers, 1 oz outer copper and ENIG. Assembly requires edge rails; panelization guidance needs careful reconciliation with the actual exported color files. [Official workflow](https://jlcpcb.com/help/article/how-to-design-multi-color-silkscreen-using-easyeda).

Our KiCad project plus an arbitrary image upload is not yet a compliant package. Their white-mask requirement leaves preservation of our opposite black optical face unresolved; a black printed overlay is not assumed optically equivalent to black mask.

Their general silkscreen guide recommends 0.15 mm lines and 0.8 mm text. The current 0.14 mm dots are smaller than that general line recommendation; obtain full-color-specific approval or revise the dots before fabrication. [General silkscreen guidance](https://jlcpcb.com/blog/pcb-silkscreen-printing-guide). This is not evidence of a confirmed 0.15 mm full-color dot limit.

## MacroFab — custom color possible; multicolor artwork unconfirmed

Lists standard colors and custom colors on request. Published rules include 0.127 mm minimum silkscreen size and 0.8 mm text height. These do not establish support for full-color image printing or exact matching of six adjacent colors. [Official capabilities](https://www.macrofab.com/capabilities).

Ask whether its fabrication partner can perform multicolor UV artwork plus assembly, with the existing black optical face. Treat this as a custom process inquiry, not a standard supported option.

## What needs a physical proof

The six deep board colors are design targets. Substrate, white underbase, ink, surface finish and curing can alter the result. Neither a hex code nor this screen rendering establishes a press color guarantee. The card uses deliberately lighter related tints, so the intended match is hue family rather than identical darkness across paper and PCB.

Before ordering the boards, request an actual-size sample or coupon with these swatches, 0.14 mm dots at 0.28 mm pitch, the smallest existing labels and the desired pad clearances. Ask for registration tolerance, minimum printable features, repeat-order color consistency, cleaning/reflow behavior, and the preferred image color space. Do not invent a CMYK conversion without the printer's process/profile.

The positioning SVG includes component illustrations and is a visual proof, not the production print layer. Prepare ink-only artwork, correct side orientation, native fab files and an explicit optical-face restriction before a supplier release. The board's 15.875 mm diameter makes fine-feature and registration review more consequential than the number of colors.

## Draft supplier inquiry — not sent

We are evaluating matte full-color artwork for the circuit face of a 15.875 mm circular, two-layer sensor PCB. The opposite optical face must retain its existing black solder mask, LED placement and optical window. Can your process print six adjacent muted color areas with white references and black dotted borders, while leaving all pad openings clear? Please confirm minimum text/line/dot sizes, registration and color tolerance, artwork/color-space requirements, assembly/reflow compatibility, and whether a physical color/legibility coupon can be supplied before a board order. Please explicitly confirm preservation of the opposite optical mask rather than substituting black printed ink.

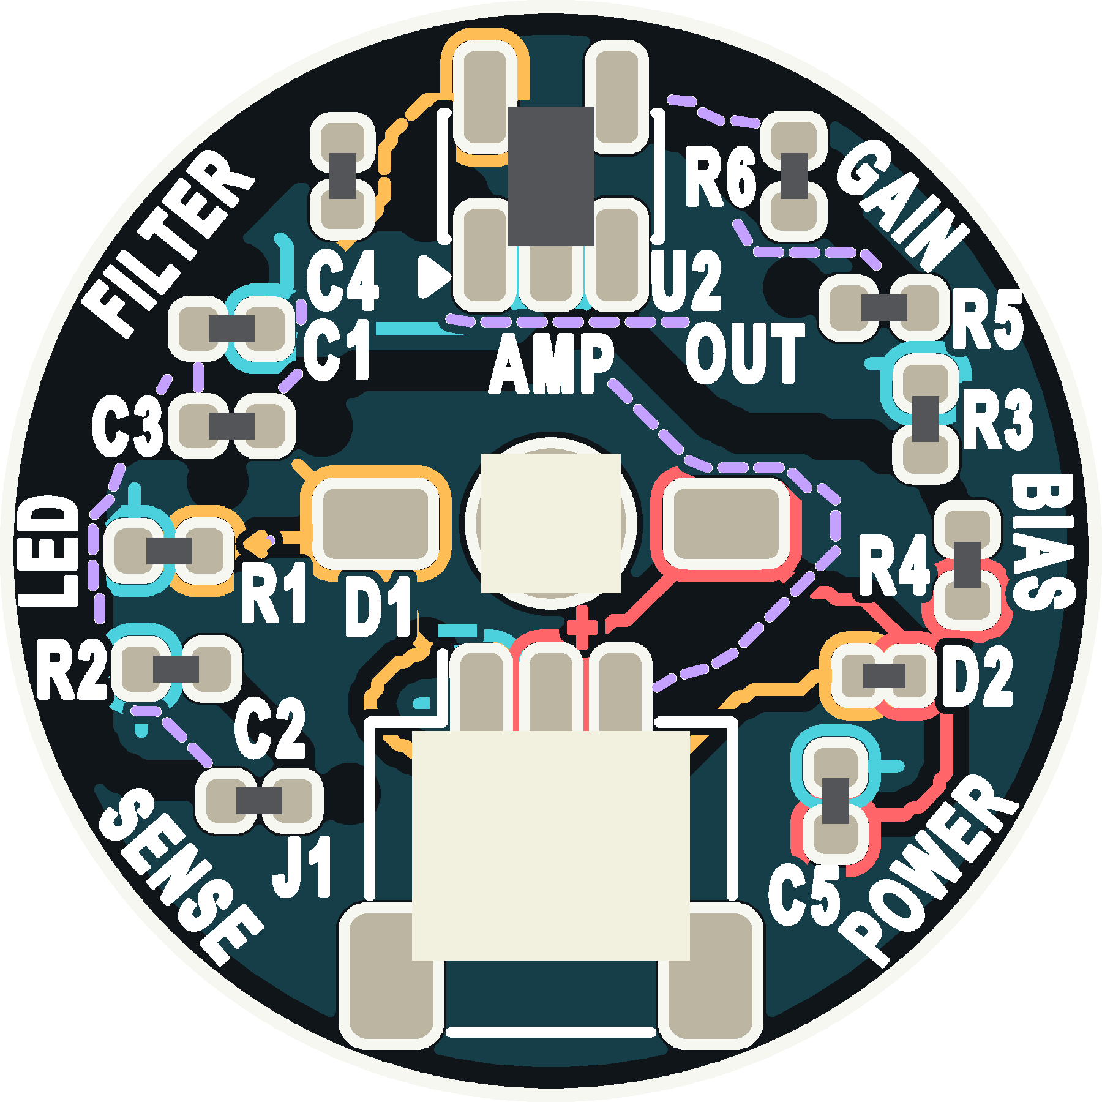
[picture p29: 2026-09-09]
review/power-color-2026-09-09/color-10-package/UV_PRINT/back.png

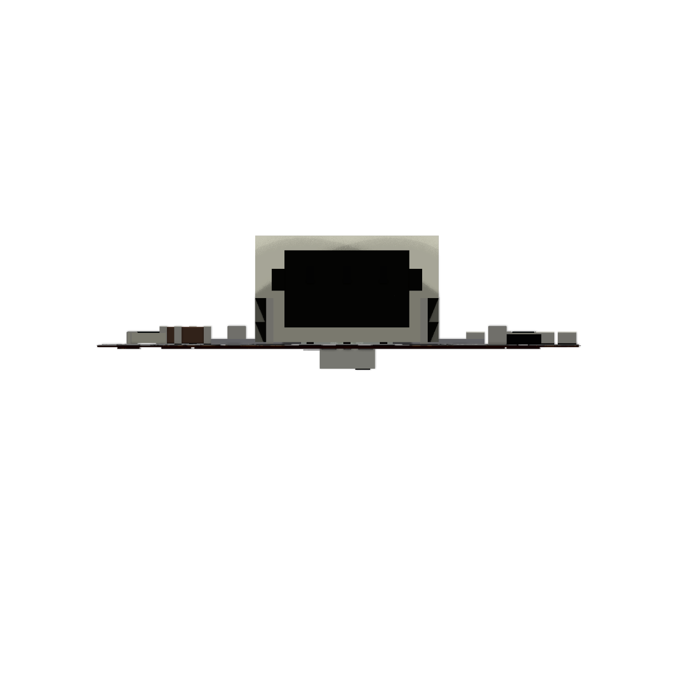
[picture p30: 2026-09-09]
review/sendoff-candidate-2026-09-09/manufacturing-review-candidate/REVIEW/edge-front.png

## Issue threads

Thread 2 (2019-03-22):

Incorrect pins in schematic of APDS-9008

wbadry, 2019-03-22:
Hello,
I believe there is a mistake in the schematic regarding **APDS-9008 pin connection**

Used pins are supposed to be 1,4 and 6
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

On schematic, it is 1,3 and 4
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

biomurph, 2019-03-22:
Actually, it is correct-ish.
If you look at the footprint for the part, I am omitting the component pins 2 and 5, since they are unused in the circuit. This makes the piece a little easier for my CM to produce, and alot easier if someone wants to make their own.

wbadry, 2019-03-22:
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

it is not about omitting the **NC pins** which I agree with. It is about the pin number that is incorrect in the schematic leading to definitely wrong connection diagram.

|  Pins (APDS-9008) | Vcc | GND | Iout |
|:-----------------:|:---:|:---:|:----:|
|   Your schematic  |  1  |  3  |   4  |
|     APDS-9008     |  1  |  4  |   6  |

The datasheet can be fetched from [here](https://www.google.com/url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). You did a great job. It is just a note for others to know, otherwise, this chip will be not work at all with current schematic. You may ofcourse correct me if mistaken.

biomurph, 2019-03-22:
Ah yes, if you follow my modified schematic it will confuse. But it happens to be connected to my footprint...
Said it was open source, didn't say it was gonna be easy. ;)

Closed 2019-03-22.

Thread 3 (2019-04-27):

PDF of schematic?

RobotGrrl, 2019-04-27:
Hi there! Long time fan of the pulse sensor. I was looking at the schematic [here](https://cdn.shopify.com/s/files/1/0100/6632/files/PulseSensorAmpd_-_Schematic.pdf?1862089645030619491) posted [on this page](https://pulsesensor.com/pages/open-hardware), but it wasn't clear to me if this is the newest schematic with the changes - or not.

Can you confirm if that is the most up to date schematic? If not... would it be possible to post a pdf of the schematic from the design files in this repository?

Hope you don't mind this request.
Thank you!

biomurph, 2019-04-29:
@RobotGrrl
Hey, I think we met once at an OSHWA Summit?
Yes, the schematic that you link to is basically up-to-date. One thing that you should note is that the resistor R1 needs to be tuned to the brightness of the LED. The LED we use has different brightness based on BIN code on the reel. Something to keep in mind if you're trying to make one yourself.

Closed 2024-07-29.

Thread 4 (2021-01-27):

line 1, column 1: Start tag expected.

shridharnator, 2021-01-27:
This is the error I get when I try to open the schematic. Please help.
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
 in EAGLE.

biomurph, 2021-01-27:
@sid
The designs were made with Design Spark.
Please use that software
Please read the Read Me file.

Closed 2021-01-27.

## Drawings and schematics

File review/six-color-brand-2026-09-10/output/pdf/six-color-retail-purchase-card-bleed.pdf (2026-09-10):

# FULL-COLOR FULL SCHEMATIC RETAIL PURCHASE CARD

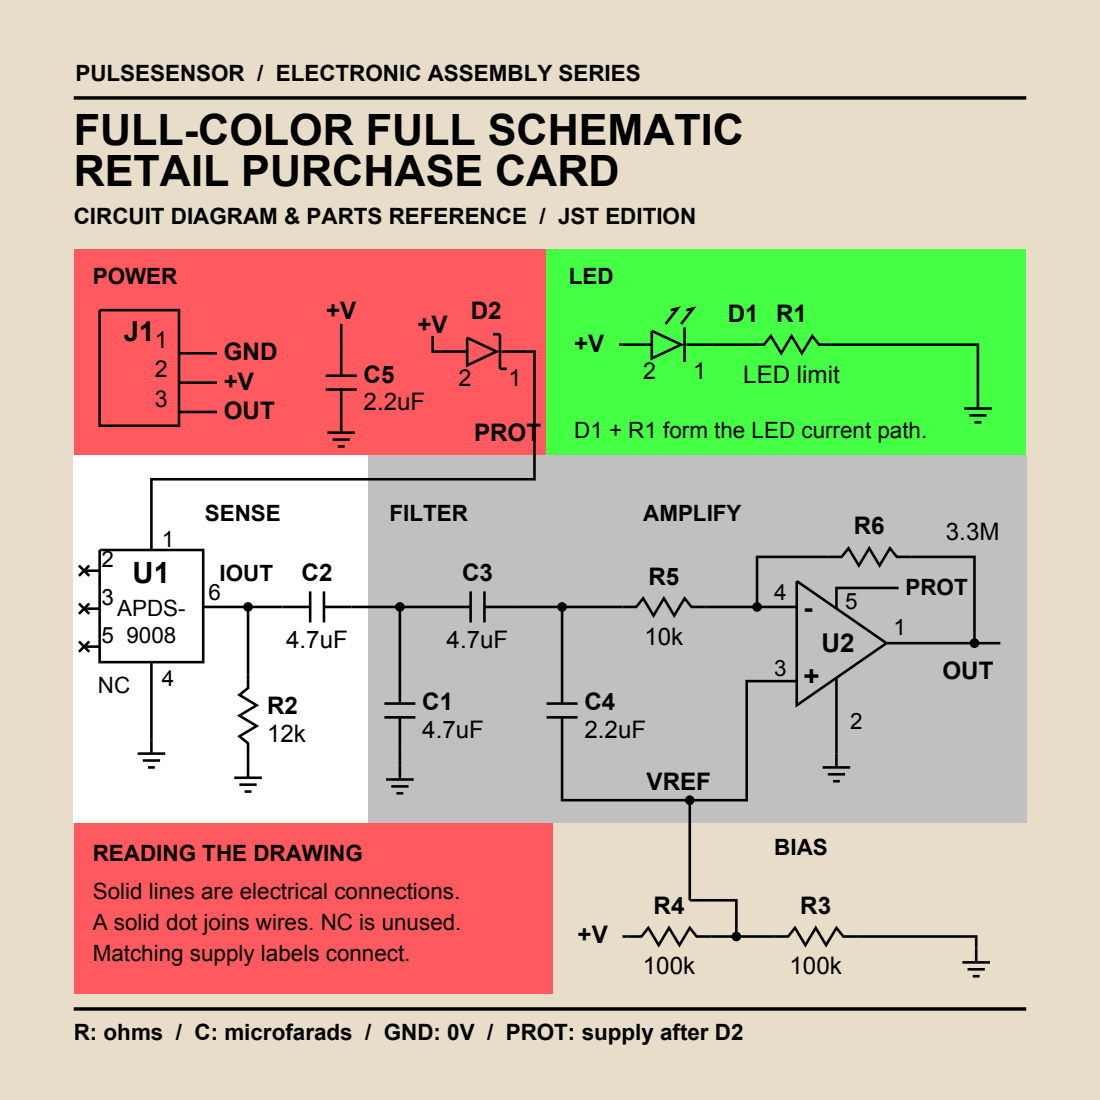
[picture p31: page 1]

PULSESENSOR / ELECTRONIC ASSEMBLY SERIES

CIRCUIT DIAGRAM & PARTS REFERENCE / JST EDITION

D1 + R1 form the LED current path.

READING THE DRAWING
Solid lines are electrical connections.
A solid dot joins wires. NC is unused.
Matching supply labels connect.

R: ohms / C: microfarads / GND: 0V / PROT: supply after D2

PULSESENSOR / ELECTRONIC ASSEMBLY SERIES

# BENCH REFERENCE

Keep this card beside the circuit board.

PARTS SCHEDULE

MARKING | VALUE / TYPE | PURPOSE
R1 | LED current limiter | Limits LED current
R2 | 12k ohm | Current-to-voltage load
R3, R4 | 100k ohm each | Reference divider
R5 | 10k ohm | Amplifier input
R6 | 3.3M ohm | Amplifier feedback
C1, C3 | 4.7uF each | Filter network
C2 | 4.7uF | Input coupling
C4 | 2.2uF | Filter to reference
C5 | 2.2uF | Supply bypass
D1 | Green LED | Illumination branch
D2 | Schottky diode | Protected chip supply
U1 | APDS-9008 | Sensor chip
U2 | MCP6001 | Operational amplifier
J1 | 3-pin JST SH | Power and output

HOW TO FOLLOW THE CIRCUIT
U1 and R2 feed the capacitors. Follow the solid line to U2.
R6 returns OUT to the - input. VREF sets the + input midpoint. The color tints match the functional areas on the PCB.
J1 pins: 1 GND (-) | 2 +V | 3 OUT

OPEN HARDWARE / pulsesensor.com

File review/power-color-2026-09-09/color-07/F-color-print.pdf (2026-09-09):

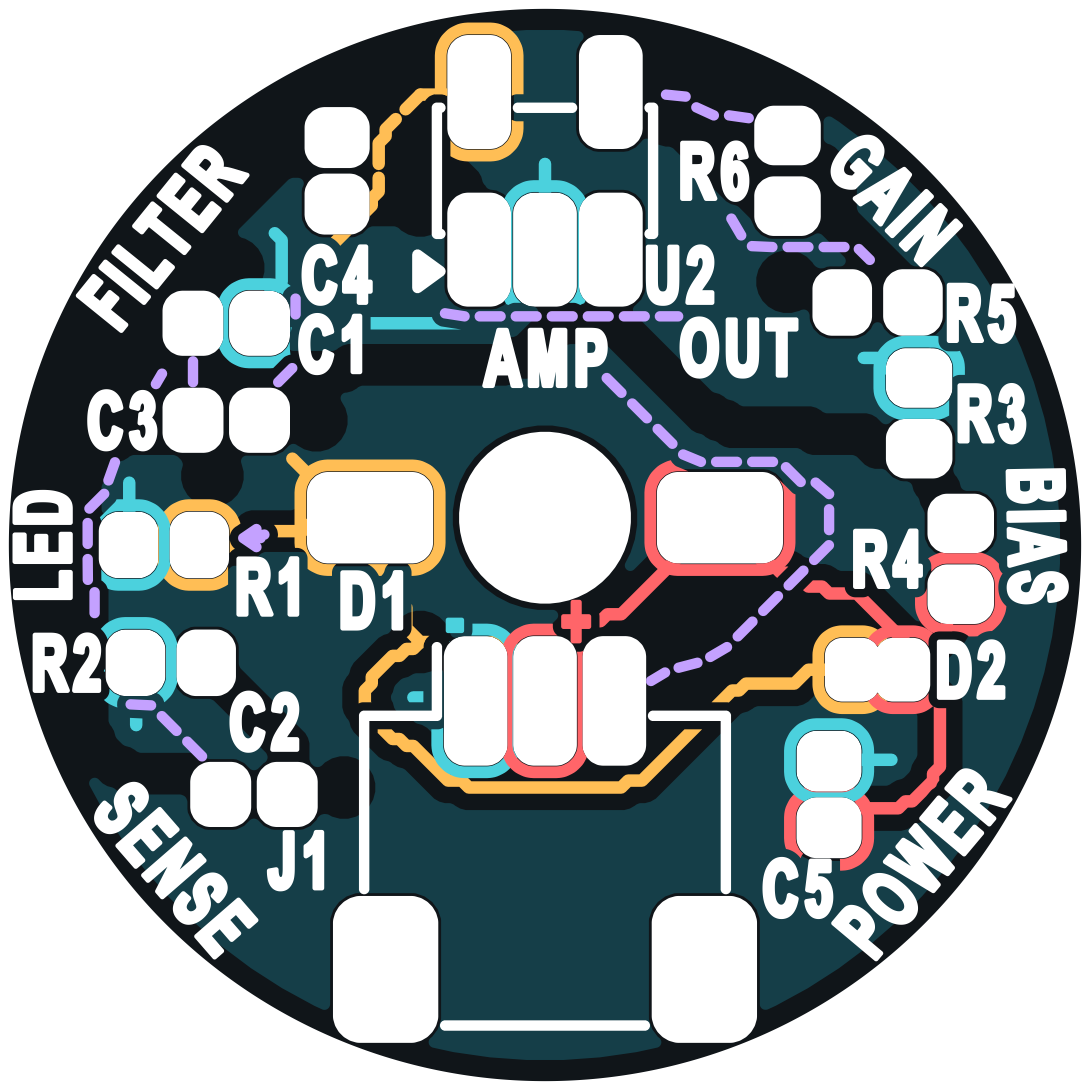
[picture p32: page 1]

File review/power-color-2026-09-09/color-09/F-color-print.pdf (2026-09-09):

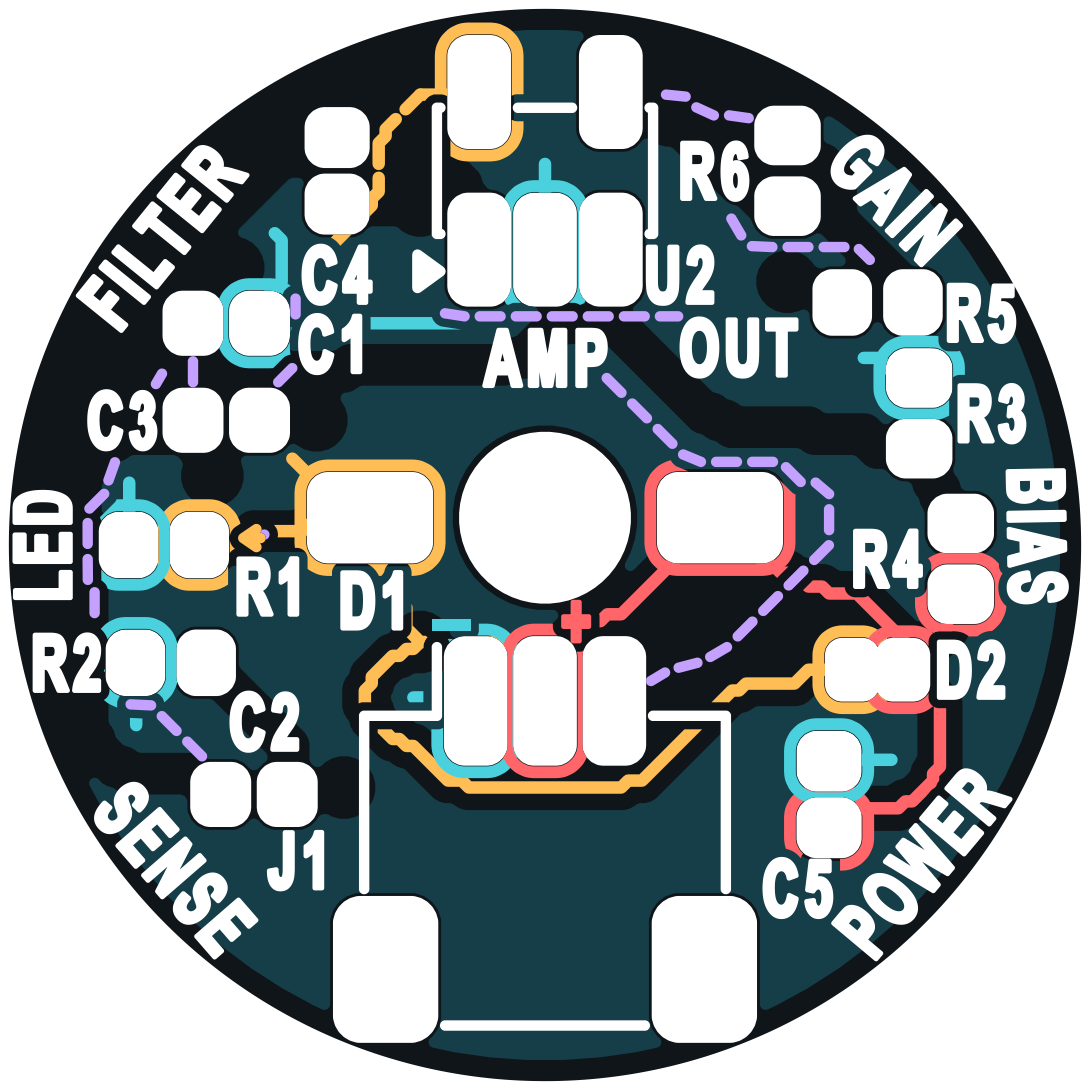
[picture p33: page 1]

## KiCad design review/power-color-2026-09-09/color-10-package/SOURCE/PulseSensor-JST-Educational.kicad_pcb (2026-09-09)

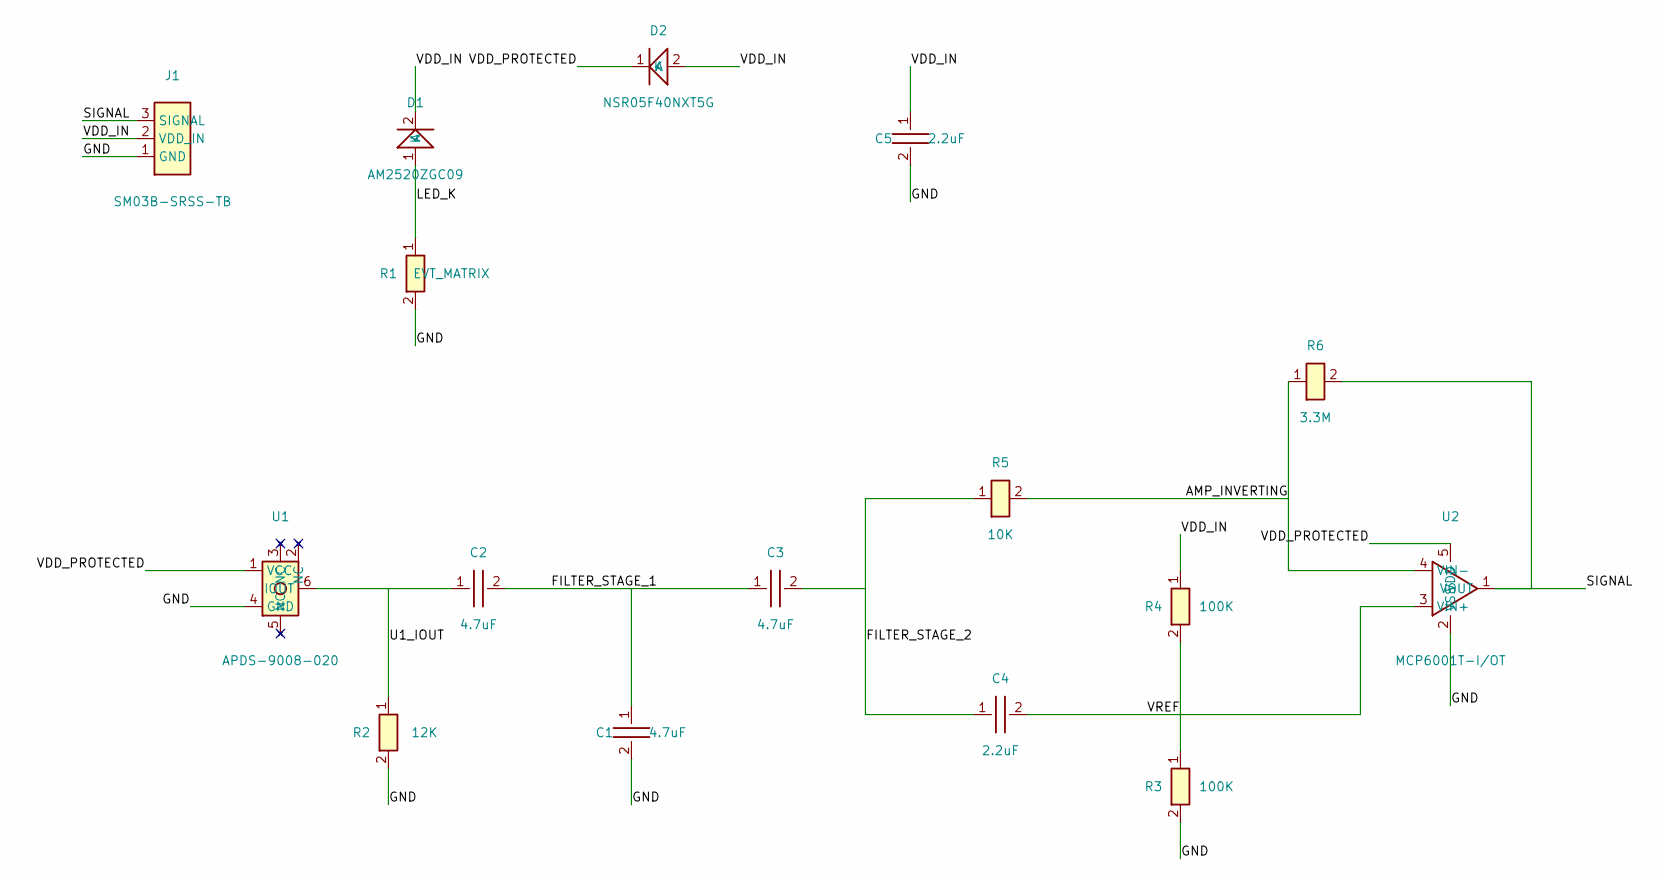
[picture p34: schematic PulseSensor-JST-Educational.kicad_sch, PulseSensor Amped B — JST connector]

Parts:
C1, C2, C3: 4.7uF; C_0402_Educational; MPN GRM155R60J475ME47D
C4, C5: 2.2uF; C_0402_Educational; MPN GRM155R61A225KE01D
D1: AM2520ZGC09; AM2520ZGC09_ReverseMount_OriginalAperture; MPN AM2520ZGC09
D2: NSR05F40NXT5G; NSR05F40NXT5G_DSN2; MPN NSR05F40NXT5G
J1: SM03B-SRSS-TB; JST_SH_SM03B-SRSS-TB_1x03-1MP_P1.00mm_Horizontal; MPN SM03B-SRSS-TB
R1: EVT_MATRIX; R_0402_Educational; MPN SEE_R1_SCREENING_MATRIX
R2: 12K; R_0402_Educational; MPN RC0402FR-0712KL
R3, R4: 100K; R_0402_Educational; MPN RC0402FR-07100KL
R5: 10K; R_0402_Educational; MPN RC0402FR-0710KL
R6: 3.3M; R_0402_Educational; MPN RC0402FR-073M3L
U1: APDS-9008-020; MPN APDS-9008-020
U2: MCP6001T-I/OT; SOT-23-5; MPN MCP6001T-I/OT

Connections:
/AMP_INVERTING: R5.2, R6.1, U2.4 (VIN-)
/FILTER_STAGE_1: C1.1, C2.2, C3.1
/FILTER_STAGE_2: C3.2, C4.1, R5.1
/GND: C1.2, C5.2, J1.1 (GND), R1.2, R2.2, R3.2, U1.4 (GND), U2.2 (VSS)
/LED_K: D1.1 (K), R1.1
/SIGNAL: J1.3 (SIGNAL), R6.2, U2.1 (VOUT)
/U1_IOUT: C2.1, R2.1, U1.6 (IOUT)
/VDD_IN: C5.1, D1.2 (A), D2.2 (A), J1.2 (VDD_IN), R4.1
/VDD_PROTECTED: D2.1 (K), U1.1 (VCC), U2.5 (VDD)
/VREF: C4.2, R3.1, R4.2, U2.3 (VIN+)

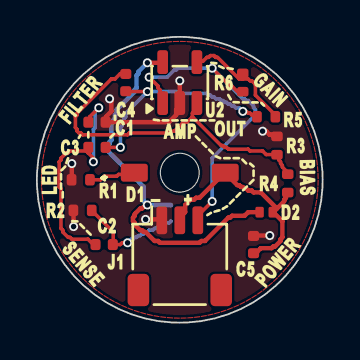
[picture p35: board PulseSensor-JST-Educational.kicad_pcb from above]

Board: 2 copper layers, 15.9 x 15.9 mm, 16 parts (1 on the bottom side), 10 nets.

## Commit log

2017-08-30 Update License And Verify Files
    [Pulse Sensor Amped BOM.xls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]
2017-08-31 Updated .pcb file
    The previous .pcb file had extraneous text on it.
2025-12-01 Update gerber files in the Plots folder
    Somehow, the bottom layers were missing information. It's all there now.
    [PulseSensorAmpd_1 - Bottom Copper.gbr, PulseSensorAmpd_1 - Bottom Solder Mask.gbr, PulseSensorAmpd_1 - Drill Data - [Through Hole] (Unplated).drl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]
2025-12-02 Replaced mistakenly removed files
    [PulseSensorAmpd_1 - Drill Data - [Through Hole] (Unplated).drl, PulseSensorAmpd_1 - Drill Data - [Through Hole].drl]
2026-09-09 Preserve paired visual index of existing Amped board designs
2026-09-09 Add PulseSensor teaching visuals and native artwork feasibility study
    [PulseSensor-JST-Educational-Study.kicad_pcb]
2026-09-09 Add educational JST PCB review candidate and manufacturing evidence
    [BOM-controlled-components.csv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]
2026-09-09 Add larger front artwork, polarity marks and PCBWay color print iteration
    [BOM-controlled-components.csv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]
2026-09-10 Add hardware-only 4-inch circuit postcard with reference BOM
2026-09-10 Add complete schematic companion postcard and reading guide
2026-09-10 Explore interlocking module backgrounds on board back
2026-09-10 Create full-color continuous schematic retail card with vintage treatment
2026-09-10 Unify board and purchase card with verified PulseSensor website palette
2026-09-10 Apply bright WebSerial palette to board and retail card
2026-09-10 Make LED sections green and power sections red
2026-09-10 Try six-color brand palette across board and retail card
